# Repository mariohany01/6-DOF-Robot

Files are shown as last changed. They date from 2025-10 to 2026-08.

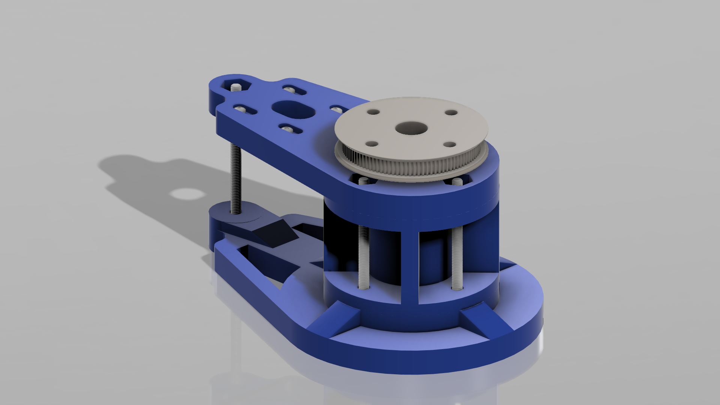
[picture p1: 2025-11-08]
Phase 1 Design, Kinematics & Core Theory (The Digital Foundation)/1 Conceptual Design & CAD/Pics/Joints/Base_Joint.png

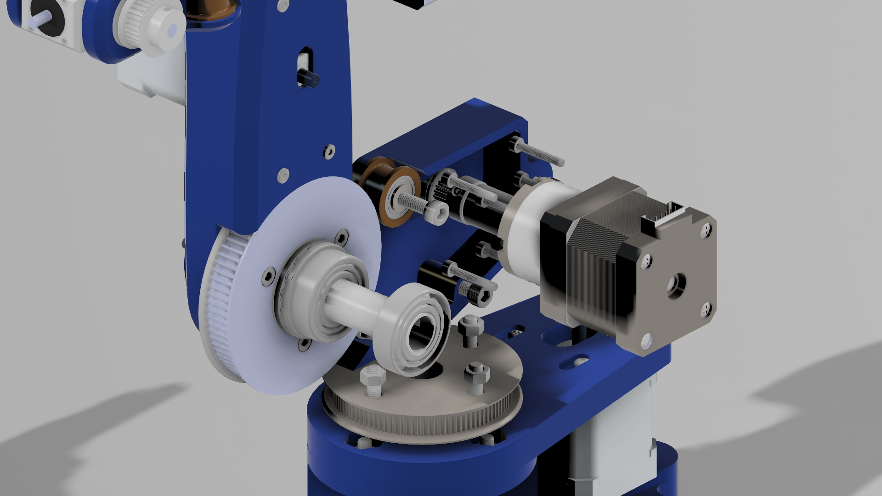
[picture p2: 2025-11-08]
Phase 1 Design, Kinematics & Core Theory (The Digital Foundation)/1 Conceptual Design & CAD/Pics/My_Kuka_07.png

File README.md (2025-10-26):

# 6-DOF KUKA-Style Robotic Arm

This is an end-to-end open-source project to design, simulate, and build a 6-DOF (Degrees of Freedom) robotic arm inspired by the KUKA industrial robot.

The project is a public journal following a 19-step roadmap, covering the entire professional engineering pipeline from initial theory to a fully functional, ROS-controlled physical robot.

## Project Phases

This repository is organized according to the 5-phase project plan:

1.  **Phase 1: Design, Kinematics & Core Theory**
    * Conceptual Design & CAD.
    * Kinematic Modeling (DH Parameters).
    * Forward & Inverse Kinematics (FK/IK)
    * Jacobian, Singularities & Velocity Control.
    * Dynamics Modeling.
    * MATLAB GUI Application.

2.  **Phase 2: Simulation & Path Planning**
    * Trajectory Planning.
    * URDF Generation.
    * Multi-Platform Simulation.

3.  **Phase 3: Advanced Control & HIL**
    * Control System Theory.
    * Simulink & Simscape Model.
    * Model-in-the-Loop (MIL) / Hardware-in-the-Loop (HIL).

4.  **Phase 4: ROS Integration & Virtual Deployment**
    * ROS Environment Setup.
    * RViz & MoveIt! Setup.
    * Gazebo Simulation Integration.

5.  **Phase 5: Physical Build & ROS Deployment**
    * Fabrication & Assembly.
    * Hardware Interface.
    * Final System Deployment.
    * Teleoperation / "Sync" Mode.

## Tech Stack

* **CAD:** SolidWorks
* **Kinematics & Control Design:** MATLAB, Simulink, Simscape
* **Robotic OS:** ROS (Robot Operating System)
* **Simulation:** Gazebo, CoppeliaSim, RViz , RoboDK
* **Path Planning:** MoveIt!
* **Hardware:** Raspberry Pi, Stepper Motors, 3D Printed Parts
* **Core Programming:** Python, C++

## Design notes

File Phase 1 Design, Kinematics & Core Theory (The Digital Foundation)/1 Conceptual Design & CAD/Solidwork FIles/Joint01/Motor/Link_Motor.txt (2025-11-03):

https://ampere-electronics.com/product/nema17-stepper-motor-with-5-181-planetary-gearbox-17hs4401s-pg518/

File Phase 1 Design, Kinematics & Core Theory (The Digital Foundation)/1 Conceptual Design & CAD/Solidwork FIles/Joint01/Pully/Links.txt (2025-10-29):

Idler Pully

https://ampere-electronics.com/product/20teeth-gt2-idler-pulley-6mm-width-3mm-bore/

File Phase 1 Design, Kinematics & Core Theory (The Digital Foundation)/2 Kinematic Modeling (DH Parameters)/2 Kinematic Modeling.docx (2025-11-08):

# 2 Kinematic Modeling (DH Parameters)

To analyze the manipulator's motion, a kinematic model was developed using the Standard Denavit-Hartenberg (DH) convention [1]. The coordinate frames assigned to each of the six joints are illustrated in Figure 1. Based on this frame assignment, the manipulator's kinematic parameters were derived. The fixed link parameters are defined as:

a1=135.80mm, a2=160.00mm, a3=15.00mm

d1=37.50mm, d2=138.10mm,d3=28.20mm

The complete set of DH parameters for the joints is presented in Table 1.

i | θ | d | a | α
1 | θ 1 | d1 | a1 | 90°
2 | θ 2+90° | 0 | a2 | -180°
3 | θ 3 | 0 | a3 | -90°
4 | θ 4 | d2 | 0 | 90°
5 | θ 5 | 0 | 0 | -90°
6 | θ 6 | d3 | 0 | 0°

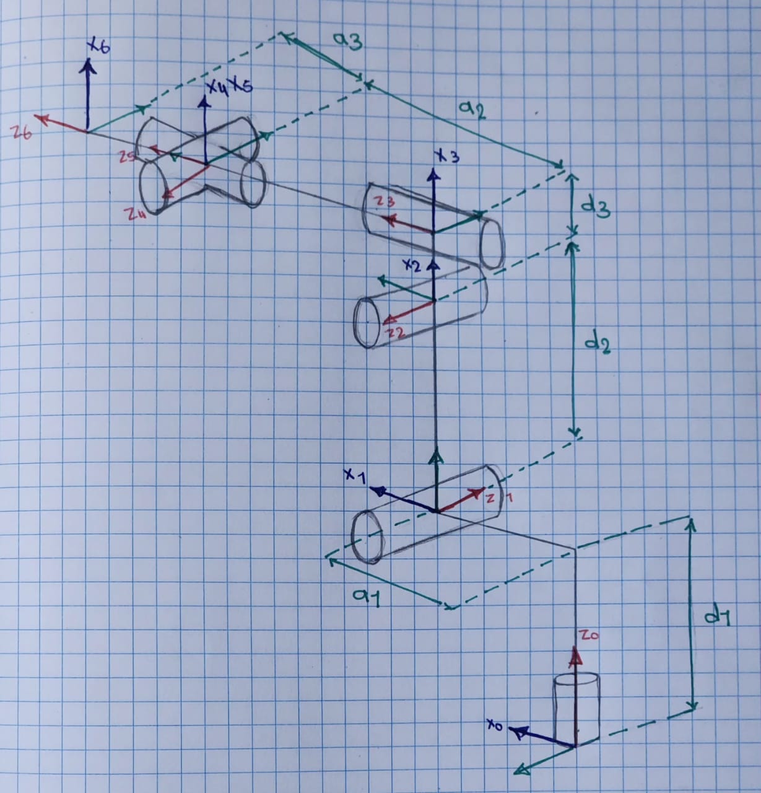
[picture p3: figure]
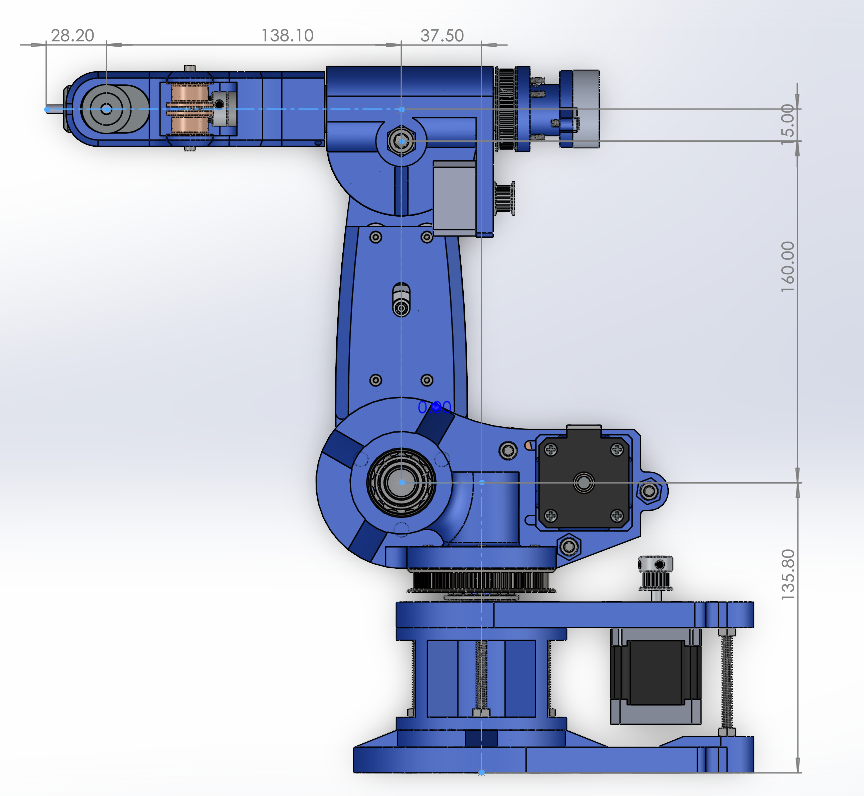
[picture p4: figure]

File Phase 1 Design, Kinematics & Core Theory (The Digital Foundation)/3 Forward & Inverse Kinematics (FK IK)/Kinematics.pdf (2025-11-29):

## FORWARD AND INVERSE KINEMATICS SOLUTION FOR 6-DOF MANIPULATORS WITH OFFSETS AND SPHERICAL WRISTS

## ABSTRACT

This research presents a comprehensive, analytical solution for the forward and inverse kinematics of a 6-DOF industrial robot, specifically focusing on a common configuration that includes both joint offsets and a spherical wrist. The forward kinematics solution is established using the standard Denavit-Hartenberg (DH) convention. For the inverse kinematics, a geometric solution is employed, which is chosen for its intuitive and interpretable nature. This method uses kinematic decoupling, solving the problem by dividing the manipulator into two 3-DOF mechanisms: the first three joints for positioning the wrist center, and the final three spherical wrist joints for orientation.

The primary contribution of this work is the validation of the geometric decoupling method against the forward kinematic model, demonstrating that the analytical approach yields exact solutions without the iterative errors inherent in numerical solvers.

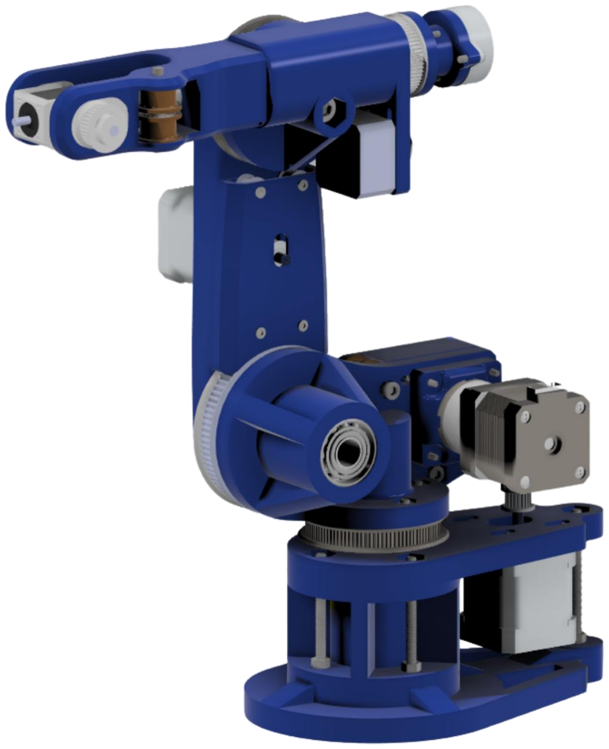
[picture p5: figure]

Eng Mario El-Assal

FORWARD AND INVERSE KINEMATICS SOLUTION FOR 6-DOF MANIPULATORS WITH OFFSETS AND SPHERICAL WRISTS

2 | Eng Mario El-Assal

## 1. INTRODUCTION

Industrial robotic manipulators are a critical component in modern automation, with 6-DOF (Degrees of Freedom) serial-chain arms, such as those from KUKA, representing common and versatile morphology. The effective implementation of any control system, motion planner, or simulation for these robots is fundamentally dependent on a precise and computationally efficient kinematic model. Kinematics, the description of motion without consideration of the forces and torques that cause it, provides the essential mapping between the robot's configuration in joint space and the pose of its end-effector in the operational task-space.

This paper presents the complete forward and inverse kinematic analysis of a custom-designed 6-DOF manipulator. The objective is to derive a robust mathematical model that serves as the foundation for future control and trajectory planning tasks.

The analysis is performed in a sequential manner. First, the robot's structure is parameterized using the Standard Denavit-Hartenberg (DH) convention. This process involves the systematic assignment of coordinate frames to each of the robot's six joints to derive a concise set of parameters (a, i, θ, α) that define the manipulator's geometry.

Second, these DH parameters are used to solve the Forward Kinematics (FK) problem. By developing the homogeneous transformation matrices for each link, the composite transformation from the robot's base frame to the end-effector frame is formulated. This allows for the direct computation of the end-effector's position and orientation for any given set of joint angles.

Finally, the Inverse Kinematics (IK) problem is addressed. This involves determining the set of joint angles (q1

. . . q2)
required to position the end-effector at a specific, desired pose (position and orientation) in its workspace.

### 1. Algebraic Solution

Solves the non-linear equations from the forward kinematics transformation Tn

0
(q) = Tdesired.
- Advantages: Robust and efficient for real-time use when a closed-form solution exists; independent of the DH convention; effective for simple manipulators (≤3 DOF).
- Limitations: Poor scalability—complexity grows exponentially with DOF and link offsets, making it impractical for most 6-DOF manipulators.

### 2. Geometric Solution

Decomposes the manipulator’s geometry into 2D trigonometric problems using the DH convention.

- Advantages: Fast and deterministic; widely used for 6-DOF manipulators (especially with spherical wrists); compatible with standard DH modeling.
- Limitations: Produces multiple valid solutions (e.g., elbow-up/down); must handle kinematic singularities where DOFs are lost.

### 3. Quaternion Solution

Uses 4D quaternions to represent and solve rotations.

- Advantages: Compact formulation; avoids gimbal lock; fewer equations.
- Limitations: Mathematically less intuitive; mainly suited for rotational systems; results less physically interpretable.

The resulting kinematic model provides the necessary foundation for all higher-level tasks, including singularity analysis, trajectory planning, and the future development of dynamic controllers for the manipulator.

Given that the kinematic structure under study involves rotational motion for each degree of freedom (DOF), employing a quaternion-based formulation would provide the most mathematically robust representation. However, for the purposes of clarity and intuitive understanding, this paper adopts a geometric solution approach. Although the robot joints exist in three-dimensional space, they are projected onto a single plane to simplify the analytical process. The spatial separations between consecutive joints are referred to as offsets. The exampled manipulator features two such offsets: one located between the first and second joints, and another between the third and fourth joints.

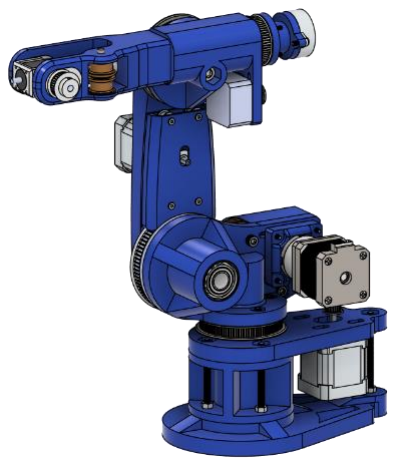
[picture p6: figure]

Figure 1. An example robot CAD model

The fourth, fifth, and sixth joints collectively constitute a spherical wrist configuration. Accordingly, the six-degree-of-freedom (6-DOF) manipulator is decomposed into two subsystems: the first comprising joints one through three, and the second encompassing the spherical wrist assembly. It is important to note that the inverse kinematics (IK) of such systems inherently yield multiple possible joint configurations for a given end-effector pose. This phenomenon has been extensively addressed in prior research. In this study, only a single representative solution is presented—specifically, the one that provides the broadest and most continuous range of motion across the manipulator’s workspace.

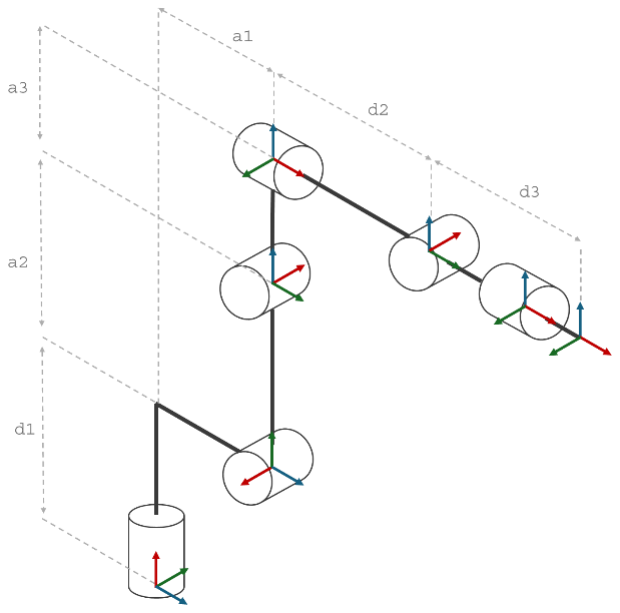
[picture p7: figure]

Figure 2. Schematic of robot shown at Figure 1

## 2. ROBOT VARIABLES, PARAMETERS & DENAVIT HARTENBERG TABLE

A very commonly used 6-DOF robot has the following variables, parameters, parameters and corresponding Denavit-Hartenberg (DH) table. In this section, these known and unknown will be exposed using the schematics in previous section.

### 2.1 Variables

The 6-DOF robot manipulator consists of six revolute joints, each providing one rotational degree of freedom. By adjusting the rotation of these joints, the robot can position its end-effector to perform the desired tasks. The primary kinematic variables of the system are the six revolute joint angles, denoted as θ. At the home position, all joint angles are defined as 0°, and during operation each angle must remain within the range of −180° to +180°.

Through this paper and its supplementary materials, the following notation is used:

Subscript | Description
θ | Joint angle
n = 1 … 6 | Indicates the joint number, counted from the base (joint 1) to the end-effector (joint 6)
v | Variable joint angle (active rotation from home position)
ℎ | Home offset angle at the home position
f | Joint angle used in forward kinematics (includes both variable and home offset components)
i | Joint angle used in inverse kinematics (includes both variable and home offset components)

Table 1: Table of Subscripts

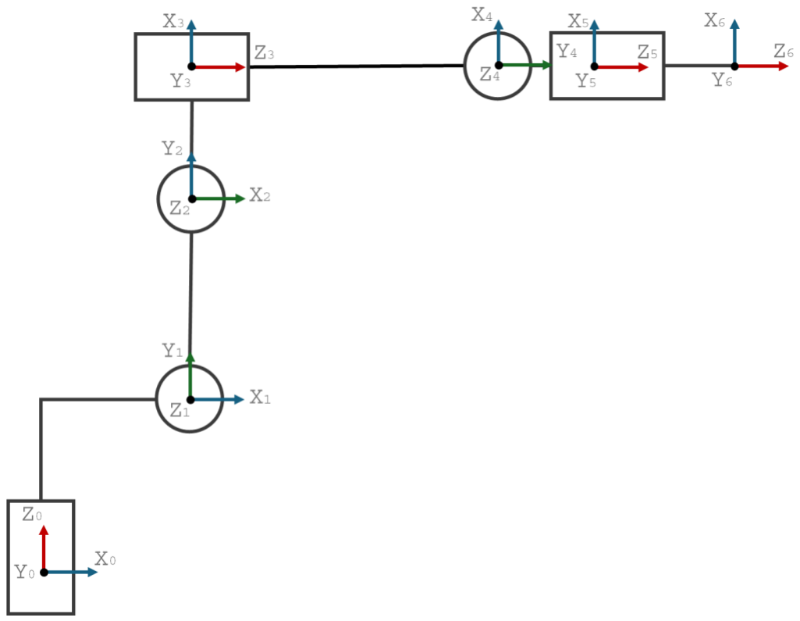
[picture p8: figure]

Figure 3: 2D Representation of schematics on Figure 2

### 2.2 Parameters & Denavit-Hartenberg Table

For the specified home position illustrated in Figures 2 and 3, the robot’s geometry is defined using the Denavit–Hartenberg (DH) convention. In this representation, each link and joint of the 6-DOF manipulator is described by four parameters: joint angle (θ), link twist (α), link offset (d), and link length (a). Each row of the DH table corresponds to one joint, resulting in a 6×4 table that fully characterizes the manipulator’s kinematic chain.

The definitions of the DH parameters are as follows:

- θ — Angle about the previous Z-axis, measured from the old X-axis to the new X-axis.
- α — Angle about the new X-axis, measured from the old Z-axis to the new Z-axis.
- d — Offset distance along the previous Z-axis, from the old joint to the new joint center.
- a — Length along the new X-axis, from the old joint to the new joint center.

When assigning local coordinate frames, the following conventions are applied:

- The Z-axis coincides with the joint axis — rotational for revolute joints or translational for prismatic joints.
- The X-axis is chosen to be perpendicular to both the previous and current Z-axes, intersecting them when possible.
- The Y-axis is determined according to the right-hand rule based on the orientations of the X and Z axes.

By following these conventions and using the geometric constraints illustrated in Figures 2 and 3, the complete DH parameter set of the robot manipulator (summarized in Table 1) can be derived. Proper placement and orientation of the local coordinate frames are critical steps in constructing the DH table, as they directly affect the simplicity and clarity of the kinematic model.

link(i) | θi | di | ai | αi
1 | θ1 | d1 | a1 | 90°
2 | θ2 + 90° | 0 | a2 | −180°
3 | θ3 | 0 | a3 | −90°
4 | θ4 | d2 | 0 | 90°
5 | θ5 | 0 | 0 | −90°
6 | θ6 | d3 | 0 | 0°

Table 2: D-H Parameters of robot manipulator that’s schematics shown in Figure 2&3

In summary, the forward kinematics of the manipulator are determined by treating each joint’s rotation angle as a variable. Since every joint is characterized by four Denavit–Hartenberg (DH) parameters, a 6-DOF robot has six joint variables and a total of 6×4 = 24 DH parameters that collectively define the end-effector’s position in Cartesian space (x, y, z) and its three orientation angles.

For forward kinematics analysis, these six joint variables always remain the fundamental unknowns, regardless of whether the mechanism has 2, 3, or 10 degrees of freedom. Increasing the number of DOF has minimal impact on the forward kinematics process; however, the same cannot be said for inverse kinematics. As the number of joints and their configurations increase, the complexity of solving the inverse kinematics problem also grows, and certain analytical methods may no longer be applicable.

## 3. FORWARD KINEMATICS CALCULATION

In 1955, Denavit and Hartenberg introduced a matrix-based approach for systematically assigning coordinate frames to each link in a robotic manipulator. This method enables the precise description of both translational and rotational relationships between consecutive links. The kinematic model of the robot in this study is formulated according to the Denavit–Hartenberg (D-H) convention. The transformation between any two successive joints can be expressed by substituting the corresponding D-H parameters from the table into the transformation matrix, denoted as Aₙ, where:

Anf =
[
cos θnf | −sin θnf cos αnf | sin θnf sin αnf | anf cos θnf
sin θnf | cos θnf cos αnf | cos θnf sin αnf | anf sin θnf
0 | sin αnf | cos αnf | dnf
0 | 0 | 0 | 1 | ]

When known joint parameters are put into their corresponding place in this matrix, then the following matrices are obtained for each joint starting from the base (1) to the tip (6);

A1f = [

cos θ1f | 0 | sin θ1f | a1f cos θ1f
sin θ1f | 0 −cos θ1f | a1f sin θ1f
0 | 1 | 0 | d1
0 | 0 | 0 | 1

]

A2f = [

cos θ2f | sin θ2f | 0 | a2f cos θ2f
sin θ2f | cos θ2f | 0 | a2f sin θ2f
0 | 0 | −1 | 0
0 | 0 | 0 | 1

]

A3f = [

cos θ3f | 0 | −sin θ3f | a3f cos θ3f
sin θ3f | 0 | cos θ3f | a3f sin θ3f
0 | −1 | 0 | 0
0 | 0 | 0 | 1

]

A4f = [

cos θ4f | 0 | sin θ4f | 0
sin θ4f | 0 −cos θ4f | 0
0 | 1 | 0 | d2
0 | 0 | 0 | 1

]

A5f = [

cos θ5f | 0 | −sin θ5f | 0
sin θ5f | 0 | cos θ5f | 0
0 | −1 | 0 | 0
0 | 0 | 0 | 1

]

A6f = [

cos θ6f | −sin θ6f | 0 | 0
sin θ6f | cos θ6f | 0 | 0
0 | 0 | 1 d3
0 | 0 | 0 | 1

]

For abbreviation and simplicity following notation substitutions will be used throughout this article.

Cn = cos θn

Sn = sin θn

Cab = CaCb − SaSb

Sab = CaCb + SaSb

The total transformation matrix from the robot base to the hand is as follows:

Tf = A1fA2fA3fA4fA5fA6f = [

r11f | r12f | r13f | pxf
r21f | r22f | r23f | pyf
r31f | r32f | r33f | pzf
0 | 0 | 0 | 1

]

Therefore:

- r11f = ((s1s4 + c1c4C2−3

)c5 + s5s2−3c1)c6 +(s1c4 − s4c1C2−3 )s6
- r12f = −((s1s4 + c1c4C2−3

)c5 + s5s2−3c1)s6 + (s1c4 − s4c1C2−3 )c6
- r13f = −(s1s4 + c1c4C2−3

)s5 + s2−3c1c5
- r21f = −((−s1c4C2−3 + s4c1

)c5 − s1s5s2−3)c6 − (s1s4C2−3 + c1c4 )s6
- r22f = ((−s1c4C2−3 + s4c1

)c5 − s1s5s2−3)s6 − (s1s4C2−3 + c1c4 )c6
- r23f = (−s1c4C2−3 + s4c1

)s5 + s1s2−3c5
- r31f = −(s5C2−3 − s2−3c4c5

)c6 − s4s6s2−3
- r32f = (s5C2−3 −s2−3c4c5

)s6 − s4s2−3c6
- r33f = −s5s2−3c4 − c5C2−3
- pxf = a1c1 + a2c1c2 + a3c1C2−3 + d2s2−3c1 − d3s1s4s5 − d3s5c1c4C2−3 + d3s2−3c1c5
- pyf = a1s1 + a2s1c2 + a3s1C2−3 +d2s1s2−3 − d3s1s5c4C2−3 + d3s1s2−3c5 + d3s4s5c1
- pzf = a2s2 + a3s2−3 + d1 − d2C2−3 − d3s5s2−3c4 − d3c5C2−3

The forward kinematics solution yields a 4 x 4 homogeneous transformation matrix, Tf. The upper-left 3 x 3 submatrix, TRf, is the rotation matrix

TRf = [

r11f | r12f | r13f
r21f | r22f | r23f
r31f | r32f | r33f

]

This is the Vectorial Representation (The Rotation Matrix) , This matrix describes the orientation of the end-effector frame relative to the base frame by explicitly defining the end-effector's basis vectors (n, o, a) in base coordinates:

- The n⃗ vector [r11fr12fr13f]

T
: This is the X-axis of your robot's hand (the "normal" direction), as seen from the base
- The o vector [r21fr22fr23f]

T
: This is the Y-axis of your robot's hand (the "orientation" or side-to-side direction), as seen from the base
- The a vector [r31fr32fr33f]

T
: This is the Z-axis of your robot's hand (the "approach" direction), as seen from the robot's base²

While mathematically complete, this is a non-minimal and non-intuitive way to specify a desired orientation. The nine constrained values do not correspond to simple, independent rotations, making it difficult for a user to define a target.

The unit vector shows the direction of the X, Y, Z-axis at the robot tip according to the base coordinate system. However, the expectation is to express all of these in angular form rather than vectorial. Below find how to express tip rotation in ZY′Z′′ Euler and XY′Z′′ Tait-Bryan angles. The matrices used to calculate these angles are available from.

ZY′Z′′ Euler angles of the robot tip coordinate axis to the base coordinate axis (subscript e denotes Euler)

Zef = arctan2(

ayf

axf

)

Y′ef = arctan2(

√1 − azf
2

azf

)

Z′′ef = arctan2(

ozf

−nzf

)

The translation matrix from the base coordinate system of the robot to the tip of the robot:

TTf = [

pxf
pyf

pzf ]

The transformation matrix that both includes translation and ZY′Z′′ Euler angles can be represented as

Tef =

[

pxf
pyf
pzf

Zef

Y′ef
Z′′ef]

This concludes the forward kinematics calculation. In proceeding inverse kinematics calculations derived above Tef matrix will be taken as input and θn joint rotations will be derived.

## 4. INVERSE KINEMATICS CALCULATIONS

In the previous section, the end-effector pose in Cartesian space was obtained by substituting specific joint angles into the forward kinematics model. Industrial robots, however, operate in the opposite direction. A robot controller typically receives a desired end-effector position and orientation in space, and it must compute the joint variables that achieve this pose. Determining these joint angles is the task of inverse kinematics.

Inverse kinematics is inherently more complex than forward kinematics, as it often involves solving nonlinear equations, handling multiple possible solutions, and ensuring that the resulting joint configurations are physically feasible. For a 6-DOF articulated robot, such as the arm considered in this research, these challenges become more pronounced due to the coupled rotational axes and the geometric constraints of the mechanism.

In this section, the inverse kinematics problem is formulated using the transformation matrix of the end-effector, derived previously. The matrix elements of the final transformation Tef are now treated as known inputs, and all subscripts are redefined from f to i to emphasize their role as inverse-kinematics variables. Based on this formulation, the analytical approach for obtaining joint angles will be developed and discussed.

Tei =
[

pxi
pyi
pzi
Zei

Y′ei
Z′′ei]

Once the end-effector transformation matrix Tei is defined, the rotational angles for each joint can be obtained by reconstructing the full transformation matrix in reverse. The translational component is directly accessible: the elements [pxi, pyi, pzi]occupy the upper portion of the final column of the matrix. To determine the rotational component, the rotation matrix must be expressed in terms of the Euler angles supplied as inputs. The rotation sequence corresponding to the Z Y

′ Z

′′Euler convention provides the necessary formulation for this process.

By substituting the inverse-kinematics Euler angles into the appropriate elemental rotation matrices, the complete rotation matrix is obtained. Throughout this derivation, the index iis appended to all variables to distinguish them as inverse-calculation parameters. These substitutions and notational conventions form the basis for constructing the rotation matrix used to compute the joint variables of the 6-DOF robot.

To systematically address the inverse kinematics problem, the robot is decomposed into two functional subsystems. This approach follows the conventional separation of an articulated manipulator into its positioning structure and orientation structure. The natural division occurs at the spherical wrist, where the final three joint axes intersect at a single point. By isolating the wrist center, the first three joints are used to determine the position of this point, while the remaining three joints are responsible for achieving the desired end-effector orientation. Based on this decomposition, the inverse kinematics solution is derived sequentially. The joint variables associated with the positioning subsystem are solved first, starting with θ01, θ03, and θ02, as these angles directly influence the spatial placement of the wrist center. Once the wrist position is determined, the orientation subsystem is solved through θ05, θ04, and θ06, which collectively produces the required end-effector orientation. This structured solution order ensures clarity, reduces coupling between equations, and aligns with the kinematic characteristics of the 6-DOF robot.

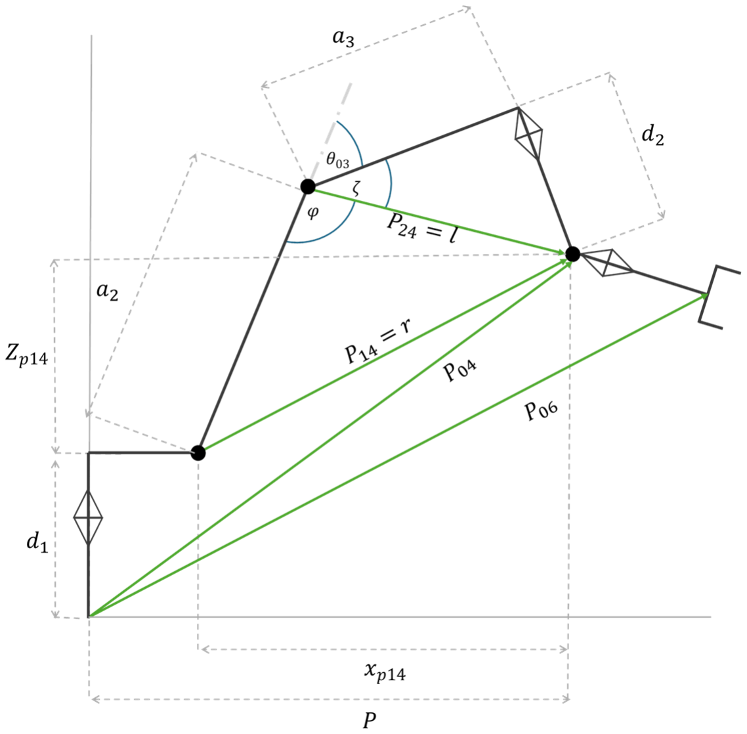
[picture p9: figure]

Figure 4: 2D Geometrical analysis for the robot

- For computational clarity, the following notation is adopted

Ann = [Rnn,nn

xnn
ynn
znn

]

Rnn,nn = [Ann,rx Ann,yx Ann,zx]

A01 = [

R01,11 | R01,12 | R01,13 | xnn
R01,21 | R01,22 | R01,23 | ynn
R01,31 | R01,32 | R01,33 | znn
0 | 0 | 0 | 1

]

A01,r = [A01,rx A01,yx A01,zx]

Pnn = [

xPnn
yPnn
zPnn

]

### 1. Solving for θ01

The wrist center position P04 is determined by deriving the input vectors from the given end-effector transformation Tei , extract the translation P06 = [pxi

, pyi

, pzi

]

T
and the end-effector z-axis unit vector a = [axi

, ayi

, azi

]

T
. The wrist centre P04(the origin of joint 4) is obtained by subtracting the end-effector offset along a:

P04 = P06 −P46

P04 = [

xP04
yP04
xP04

] = [
Pxi
Pyi

Pzi ]− d6i
[

r13
r23
r33

] = [
Pxi − d6ir13
Pyi −d6ir23

Pzi −d6ir33]

Subsequently, the angle of P04 relative to the XY-plane is calculated as

θ01 = θ01v = atan2 (
Pyi − d6ir23

Pxi − d6ir13) = atan2(yP04, xP04)

### 2. Solving for θ03

Among all six joint variables, θ03 is the most challenging to determine. Once the geometric reasoning behind θ03 is understood, the remainder of the inverse-kinematics solution becomes significantly more straightforward. To simplify this part of the geometry, a practical constraint is introduced on the allowable range of θ03, which reduces ambiguity and ensures a consistent solution for the robot configuration.

Based on law of cosines

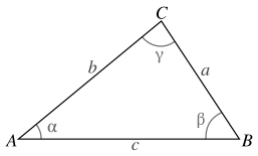
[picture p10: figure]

From the geometric projection in Figure 4, the following parameters are derived

- For P04 projection on the XY − Plane ∶ :

P = √xP04
2 +yP04

2

cos(α) =

c

2 + b

2 − c

2
2 × a × b

- For P14 projections:

xP14 = P − a1

zP14 = zP04 − d1

- Calculation of the radial distance r: r = √xP14
2 + zP14

2

- Finding the l :

l = √a3
2 + d2

2

- Using law of cosines:

c =

a2

2 + l

2 + r

2
2 × a2 × l

φ = arccos(c)

- Calculation of the fixed shoulder offset angle (ζ): ζ = atan2(d2
, a3

) = 83.8010°

- Therefore the elbow configuration:

θ03 = 180 − (φ + ζ)

### 3. Solving for θ02

- The angle θ2

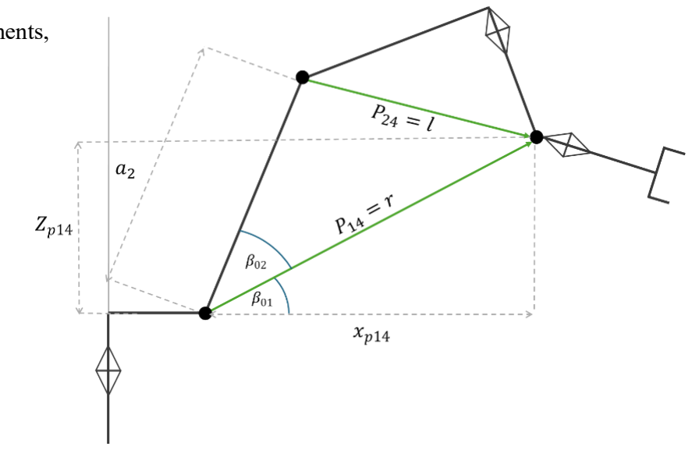
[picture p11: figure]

is decomposed into two components, β01and β02

- Finding beta 01

β01 = atan2(zp14, xp14)

- Finding beta 02

β02 = arccos (
a2

2 + r

2 +l

2
2 × a2 × r

)

- Finding theta 03

θ02 = β01 + β02

### 4. Solving for θ05

The joint angle θ5
is derived from the angle between the Z-axis of joint 4 and the z direction of joint 6
- Finding Z direction of 4th joint

A1i
= [
cos θ1f | 0 | sin θ1f | a1f cos θ1f
sin θ1f | 0 −cos θ1f | a1f sin θ1f
0 | 1 | 0 | d1
0 | 0 | 0 | 1

]

A2i
= [
cos θ2f | sin θ2f | 0 | a2f cos θ2f
sin θ2f | cos θ2f | 0 | a2f sin θ2f
0 | 0 | −1 | 0
0 | 0 | 0 | 1

]

A3i
= [
cos θ3f | 0 | −sin θ3f | a3f cos θ3f
sin θ3f | 0 | cos θ3f | a3f sin θ3f
0 | −1 | 0 | 0
0 | 0 | 0 | 1

]

A03i = A1i × A2i × A3i

- Therefore z03 =

A03,rz = [
c1

(s2c2 − c2s3

)
s1

(s2c2 − c2s3

)

−s23 ]

- And z06

A06,rz = [

r13
r23
r33

]

- Finding theta 05

θ05 = arccos(

A06,rz ⋅ A03,rz

|A06,rz||A03,rz|

)

### 5. Solving for θ04

A46i = A13i

−1 × A06i = [

Ix | Jx | Kx | Lx
Iy | Jy | Ky | Ly
Iz | Jz | Kz | Lz
0 | 0 | 0 | 1

]

- On the other hand

A46i = A4 × A5 × A6 = [

Ex | Fx | Gx | Hx
Ey | Fy | Gy | Hy
Ez | Fz | Gz | Hz
0 | 0 | 0 | 1

]

- Ex = c4c5c6 −s4s6
- Ey = c4s6 +c5c6c4
- Ez = c6s5
- Fx = −c6s4 − c4c5s6
- Fy = c4c6 −c5s4s6
- Fz = −s5s6
- Gx = −c4s5
- Gy = −s4s5
- Gz = c5
- Hx = −d3c4s5
- Hy = −d3s4s5
- Hz = d2 + d3c5
- For theta 04

θ04 = atan2 (

Ly
Lx

) +180°

### 6. Solving for θ06

θ06 = −atan2 (

Jz
IZ

)

## 5. CONCLUSION

This research presented a comprehensive analytical derivation of forward and inverse kinematics for a 6-DOF industrial manipulator featuring joint offsets and a spherical wrist. By employing the standard Denavit-Hartenberg (DH) convention, a forward kinematic model was established to successfully map joint space to Cartesian task space.

For the inverse kinematics, a geometric decomposition approach was utilized. This method effectively decoupled the positioning problem (joints 1–3) from the orientation problem (joints 4–6) by isolating the wrist center. This geometric strategy proved advantageous over algebraic or numerical iterative methods, offering a deterministic solution that accounts for the specific mechanical offsets found in KUKA-style architecture.

The resulting mathematical model provides a computationally efficient and physically interpretable framework for robot control. The validation of these equations establishes a robust foundation for high-level tasks. Future work will extend this kinematic model to implement real-time trajectory planning, singularity analysis, and dynamic control algorithms.

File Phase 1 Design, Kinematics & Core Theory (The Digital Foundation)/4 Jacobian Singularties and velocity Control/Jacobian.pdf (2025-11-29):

JACOBIAN AND VELOCITIES FOR 6-DOF MANIPULATORS WITH OFFSETS AND SPHERICAL WRISTS

## JACOBIAN AND VELOCITIES FOR 6-DOF MANIPULATORS WITH OFFSETS AND SPHERICAL WRISTS

## ABSTRACT

This research presents a comprehensive analysis of the differential kinematics for a specific 6-Degree of Freedom (DOF) Kuka serial manipulator. By defining the robot’s geometry through standard Denavit-Hartenberg (DH) parameters, we derive the forward kinematics model essential for state estimation. The core of this study focuses on the numerical computation of the Jacobian matrix, employing a finite difference approach to approximate the linear mapping between joint space velocities and task space end-effector velocities. Special attention is given to the derivation of angular velocity components using the properties of skew-symmetric matrices and the time derivative of rotation matrices. Furthermore, the practical utility of the Jacobian is demonstrated through a differential inverse kinematics control scheme, enabling precise Cartesian trajectory tracking. Detailed MATLAB implementations are dissected to illustrate the algorithmic translation of these theoretical concepts into functional simulation code.

## 1. INTRODUCTION

This research document analyzes the differential kinematics of a specific 6-Degree of Freedom (DOF) serial manipulator (Kuka-type). The focus is on the Jacobian Matrix, a critical mathematical tool that relates joint space velocities to task space (end-effector) velocities.

We will analyze the physical parameters of the robot, derive the mathematical foundation of the Numerical Jacobian, and provide a detailed, line-by-line illustration of the MATLAB implementation used for both Jacobian calculation and Inverse Kinematics control.

## 2. ROBOT DEFINITION AND KINEMATICS

### 2.1 Denavit-Hartenberg (DH) Parameters

The robot is defined using the Standard Denavit-Hartenberg parameters. These parameters describe the transformation from one link to the next.
link(i) | θi | di | ai | αi
1 | θ1 | d1 | a1 | 90°
2 | θ2 + 90° | 0 | a2 | −180°
3 | θ3 | 0 | a3 | −90°
4 | θ4 | d2 | 0 | 90°
5 | θ5 | 0 | 0 | −90°
6 | θ6 | d3 | 0 | 0°

### 2.2 Forward Kinematics (FK)

The position and orientation of the end-effector are determined by multiplying the transformation matrices of individual links:

Tglobal = A1

(q1

) · A2

(q2

) · A3

(q3

) · A4

(q4

) · A5

(q5

) · A6

(q6

)

Where each Ai

is a 4×4 homogeneous transformation matrix derived from row i of Table 1. The result is:

T = [

R3x3 | P3x1
01x3 | 1

]

## 3. THEORETICAL FOUNDATION: THE JACOBIAN

The Jacobian matrix serves as the fundamental mathematical bridge between the robot's internal joint space and the external Cartesian task space. It acts as a linear mapping operator that transforms joint velocities (q̇) directly into the end-effector's linear and angular velocities (υ, ω)by representing the matrix of partial derivatives, the Jacobian effectively linearizes the complex, non-linear forward kinematics equations around a specific operating point. This linearization is critical for differential control strategies, allowing us to calculate how infinitesimal changes in joint angles propagate to the tool tip's motion. Furthermore, the Jacobian provides essential insights into the mechanical structure, helping to identify singular configurations where the robot loses degrees of freedom.

### 3.1 What is the Jacobian Matrix?

To understand the Jacobian matrix, we must first revisit the fundamental concept of the derivative in a univariate context. Consider a single-variable function f(x) = x

2

.The derivative, denoted as df
dx

, represents the instantaneous rate of change of the function with respect to its input. For this specific function, the derivative is:

df
dx = x

2

This scalar value quantifies how the output responds to infinitesimal perturbations in the input x.

- Multivariable Scalar Functions:

Multivariable scalar functions expand into the multivariable domain; we encounter functions that accept multiple inputs simultaneously. Consider a scalar function f dependent on variables x1 and x2 defined as:

f(x1
, x2

) = x1

2 +3x1x2 + x2

2

In this context, we utilize the partial derivative to isolate the sensitivity of the function to a single variable while holding others constant. The gradient of this function is composed of its partial derivatives with respect to x1 and x2

∂f
∂x1

= 2x1 + 3x2

,

∂f
∂x2

= 3x1 + 2x2

- Vector-Valued Functions and the Jacobian:

The Jacobian matrix arises when we generalize this concept to vector-valued functions systems involving multiple input variables and multiple output functions. Let f(x) be a function mapping a vector x ∈ R

n
to a vector f ∈ R

m.
Consider the specific system defined by the vector function

f(x) = [

f1

(x1
, x2

)
f2

(x1
, x2

)

] = [

x1

2 + x2
x1 +x2

2

]

The Jacobian matrix, denoted as J, represents the linear mapping of the system's first-order partial derivatives. It describes how the output vector changes relative to changes in the input vector. For a system with two inputs and two outputs, the Jacobian is defined as:

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
By computing the partial derivatives for the system defined above:

Forf1
:

∂f1
∂x1

= 2x1 and ∂f1
∂x2

= 1

For f2
:

∂f2
∂x1

= 1 and ∂f2
∂x2

= 2x2

Substituting these terms into the matrix yields the final Jacobian for the system:

J(x) = [

2x1 | 1
1 | 2x2

]

### 3.2 Jacobian In robotics

In the domain of robotics, the Jacobian matrix (J) is not merely a mathematical abstraction but the fundamental operator connecting Joint Space (the internal configuration of motors and actuators) to the Task Space (the external position and orientation of the end-effector).

While Forward Kinematics defines a static relationship between joint angles and end-effector position, the Jacobian defines the dynamic relationship, mapping velocities and forces.

In the multivariable calculus section, we defined the Jacobian as a matrix of partial derivatives. In robotics, we apply this exact definition to motion.

The Core Equation:

v = J(q) × q̇

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
Where:

- v is the End-Effector Velocity Vector (6 × 1). It contains 3 linear velocities (vx

, vy, vz) and 3 angular velocities

(ωx, ωy, ωz).
- J(q) is the Jacobian Matrix (6 × 6 for your robot). It changes based on the robot's current pose q.
- q̇ is the Joint Velocity Vector (6 × 1). It represents how fast each motor is spinning (q1
̇ , q2

̇ , … , q6

̇ ).

What is Physical Interpretation for this part?
Each column i of the Jacobian tells you: "If I move only joint i at 1 rad/s, what is the resulting velocity vector of the end-effector?"

### 3.2.1 Calculating the Jacobian

While the Jacobian can be derived analytically, a robust method for computational implementation is the Numerical differentiation (Finite Difference) approach. This method approximates the partial derivatives by introducing a minute perturbation (δ) to each joint and observing the resulting change in the end-effector's pose.

- Step 1: Compute Initial State

First, we compute the Forward Kinematics (FK) for the current joint configuration q. This yields the homogeneous transformation matrix Tcurr

Tcurr = FK(q) = [

Rcurr | Pcurr
0 | 1

]

Where Pcurr is the position vector and Rcurr is the rotation matrix.

- Step 2: Apply Perturbation

To find the partial derivative with respect to joint i, we add a small perturbation δ (e.g., 10⁻⁶ ) to that specific joint
while keeping others constant:

qpert = q + [δ, 0,0,0,0,0]

- Step 3: Compute Perturbed State

We calculate the new Forward Kinematics based on the perturbed joints

Tpert = FK(qpert) = [

Rpert | TPert
0 | 1

]

- Step 4: Calculate Linear Velocity Component (Jv)

The linear velocity component of the Jacobian column is the rate of change of the position vector:

Jvi ≈

Ppert − Pcurr
δ

This approximates the derivative ∂P
∂qi
- Step 5: Calculate Angular Velocity Component (Jω)

Determining angular velocity requires analyzing the change in the Rotation Matrix. We compute the derivative of the rotation matrix Ṙ

Ṙ ≈

Rpert − Rcurr
δ

Using the property that Ṙ = S(ω)R,where S(ω)is the skew-symmetric matrix of the angular velocity vector , we can isolate S(ω)

S(ω) = ṘR
T

The resulting 3 × 3 Matrix S takes the form

S(ω) = [

0 | −wz | wy
wz | 0 | −wx
−wy | wx | 0

]

By applying the inverse operation (often denoted as the vex operator), we extract the angular velocity vector

Jωi = [ωx, ωy, ωz

]

T

Step 6: Construct the Column

The final i-th column of the Jacobian is the concatenation of the linear and angular components:

ji = [

jvi
jwi

]

This process is repeated for all n joints to construct the full 6 × n Jacobian matrix.

### 3.2.2 Inverse Kinematics Control (Resolved Rate Motion Control)

The Jacobian is instrumental in trajectory planning. While Forward Kinematics maps joint angles to positions, Inverse Kinematics typically seeks to find the joint angles required to reach a specific target. By utilizing the Jacobian, we can control the robot at the velocity level.

From the relationship ve = J(q)q̇, we can solve for the required joint velocities q̇ to achieve a desired end-effector

velocity vdesired:

q̇ = j

−1
(q) × vdesired

n practice, particularly for 6-DOF robots where singularities may occur, the Moore-Penrose Pseudoinverse (J

†
) is
preferred over the standard inverse to ensure numerical stability:

q̇ = J

†
(q) × vdesired

### 3.2.3 Algorithm Implementation

The implementation is developed in MATLAB. The simulation utilizes a numerical differentiation method to compute the Jacobian matrix dynamically at every time step, ensuring adaptability to the 6-DOF KUKA manipulator structure defined in the previous sections.

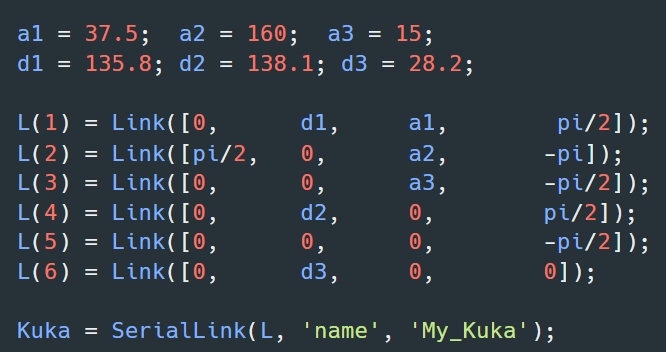
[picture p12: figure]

Block 1: Kinematic Modeling (DH Parameters)

The robot is modeled using the Denavit-Hartenberg
(DH) | convention. | The | link | parameters
( twist α, length a, offset d, and angle θ ) are defined to match the KUKA manipulator specifications.

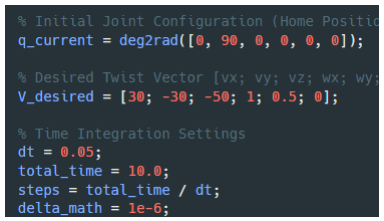
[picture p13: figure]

Block 2: Initialization and Target Definition

The simulation initializes the robot at a non-singular starting posture qcurrent . The control target is defined not as a final position, but as a velocity vector Vdesired ∈ R

6
, comprising
linear | velocity | (vx, vy, vz) and | angular | velocity

(ωx, ωy, ωz).

Block 3: The Control Loop & Numerical Jacobian

The core of the algorithm runs inside a temporal loop. At each step t, the Jacobian matrix J(q) is computed using the Finite Difference Method. Each joint is perturbed by a small delta (δ), and the resulting change in the end-effector pose is measured to approximate the partial derivatives.

Once $J$ is found, the required joint velocities are calculated using the Moore-Penrose pseudoinverse:

q̇ = J

†
(q) × vdesired

At the end

q_current = q_current + (q_dot' * dt);

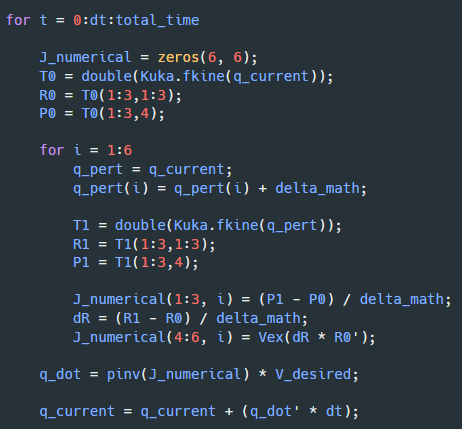
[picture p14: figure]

“You are taking the instantaneous velocity (q̇), pretending it stays constant for a tiny fraction of a

### second (dt), and "teleporting" the robot to that new spot.”

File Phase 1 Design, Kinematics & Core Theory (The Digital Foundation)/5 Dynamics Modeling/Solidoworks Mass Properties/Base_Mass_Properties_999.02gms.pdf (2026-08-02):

Mass properties of Base_Assembly Configuration: Default
Coordinate system: Base_Coordinates

Mass = 999.02 grams

Volume = 484030.20 cubic millimeters

Surface area = 166100.45 square millimeters

Center of mass: ( millimeters )
X = -36.09
Y = 0.11
Z = 41.05

Principal axes of inertia and principal moments of inertia: ( grams * square millimeters ) aTken at the center of mass.
Ix = ( 0.99, 0.00, -0.13) | Px = 1024124.32
Iy = (-0.13, 0.00, -0.99) | Py = 2453441.82
Iz = ( 0.00, 1.00, 0.00) | Pz = 2734227.60

Moments of inertia: ( grams * square millimeters )
aTken at the center of mass and aligned with the output coordinate system. (Using positive tensor notation.)
Lxx = 1046850.94 | Lxy = -5081.33 | Lxz = -178732.64
Lyx = -5081.33 | Lyy = 2734212.13 | Lyz = 761.80
Lzx = -178732.64 | Lzy = 761.80 | Lzz = 2430730.67

Moments of inertia: ( grams * square millimeters )
aTken at the output coordinate system. (Using positive tensor notation.)
Ixx = 2730644.14 | Ixy = -9098.05 | Ixz = -1658910.47
Iyx = -9098.05 | Iyy = 5719187.48 | Iyz = 5331.03
Izx = -1658910.47 Izy = 5331.03 | Izz = 3731937.63

One or more components have overridden mass properties: M5_ISO (4762)_70<91290A201>
M5_ISO (4762)_70<91290A201>
M5_ISO (4762)_70<91290A201> M5_ISO (4762)_70<91290A201> M5_ISO (4762)_70<91290A201> M3_ISO (4762)_10<92000A120> M3_ISO (4762)_10<92000A120> M3_ISO (4762)_10<92000A120> M3_ISO (4762)_10<92000A120> M5_ISO (4032)_Nut<90591A260> M5_ISO (4032)_Nut<90591A260> M5_ISO (4032)_Nut<90591A260> M5_ISO (4032)_Nut<90591A260> M5_ISO (4032)_Nut<90591A260> M5_ISO (4032)_Nut<90591A260> M5_ISO (4032)_Nut<90591A260> M5_ISO (4032)_Nut<90591A260> M5_ISO (4032)_Nut<90591A260>
M5_ISO (4032)_Nut<90591A260>
M5_ISO (4032)_Nut<90591A260>
Angular Contact Bearing (7002) 15x32x9<2385K42> Thrust ball bearing (51104) 20x35x10<7806K716> Thrust ball bearing (51104) 20x35x10<7806K716> Angular Contact Bearing (7002) 15x32x9<2385K42>

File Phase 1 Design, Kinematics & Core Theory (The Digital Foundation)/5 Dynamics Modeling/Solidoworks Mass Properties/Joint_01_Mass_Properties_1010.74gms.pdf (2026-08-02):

Mass properties of Joint01_Assembly Configuration: Default
Coordinate system: Joint01_Coordinates

Mass = 1010.74 grams

Volume = 424785.42 cubic millimeters

Surface area = 154917.10 square millimeters

Center of mass: ( millimeters )
X = -57.76
Y = -5.77
Z = -23.13

Principal axes of inertia and principal moments of inertia: ( grams * square millimeters ) aTken at the center of mass.
Ix = ( 0.85, -0.10, 0.51) | Px = 1083454.18
Iy = ( 0.52, 0.11, -0.85) | Py = 2165094.13
Iz = ( 0.02, 0.99, 0.15) | Pz = 2463913.57

Moments of inertia: ( grams * square millimeters )
aTken at the center of mass and aligned with the output coordinate system. (Using positive tensor notation.)
Lxx = 1379194.99 | Lxy = -96653.51 | Lxz = 472553.44
Lyx = -96653.51 | Lyy = 2446919.81 | Lyz = -97922.48
Lzx = 472553.44 | Lzy = -97922.48 | Lzz = 1886347.08

Moments of inertia: ( grams * square millimeters )
aTken at the output coordinate system. (Using positive tensor notation.)
Ixx = 1953704.77 | Ixy = 240460.56 | Ixz = 1822940.41
Iyx = 240460.56 | Iyy = 6359628.08 | Iyz = 37085.71
Izx = 1822940.41 | Izy = 37085.71 | Izz = 5291953.15

One or more components have overridden mass properties: Idler_Assembly
M5_ISO (4762)_16<91290A232>
M5_ISO (4762)_16<91290A232> M5_ISO (4762)_16<91290A232> M5_ISO (4762)_16<91290A232> M5_ISO (4762)_30<91290A194> M5_ISO (4762)_30<91290A194> M5_ISO (4762)_40<91290A196> M4_ISO (4762)_20<91290A123> M4_ISO (4762)_20<91290A123> M4_ISO (4762)_20<91290A123> M4_ISO (4762)_20<91290A123> M3_ISO (4762)_20<91290A123> M3_ISO (4762)_20<91290A123> M3_ISO (4762)_20<91290A123> M3_ISO (4762)_20<91290A123> M5_ISO (4032)_Nut<90591A260> M5_ISO (4032)_Nut<90591A260> M5_ISO (4032)_Nut<90591A260> M5_ISO (4032)_Nut<90591A260> M5_ISO (4032)_Nut<90591A260>
M5_ISO (4032)_Nut<90591A260>
M5_ISO (4032)_Nut<90591A260>
Angular Contact Bearing (7002) 15x32x9<2385K42> Angular Contact Bearing (7002) 15x32x9<2385K42>
Thrust ball bearing (51104) 20x35x10<7806K716>
Contact ball bearing(F695) 5x13x4<4668K115>
17HS4401S-PG518 Stepper Motor with 5.18-1 Planetary Gearbox

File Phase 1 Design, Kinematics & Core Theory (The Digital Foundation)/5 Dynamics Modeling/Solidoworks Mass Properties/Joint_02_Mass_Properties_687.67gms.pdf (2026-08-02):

Mass properties of Joint02_Assembly Configuration: Default
Coordinate system: Joint02_Coordinates

Mass = 687.67 grams

Volume = 341496.18 cubic millimeters

Surface area = 135243.10 square millimeters

Center of mass: ( millimeters )
X = -90.56
Y = 0.00
Z = -50.83

Principal axes of inertia and principal moments of inertia: ( grams * square millimeters ) aTken at the center of mass.
Ix = ( 0.99, 0.00, -0.14) | Px = 355190.74
Iy = (-0.14, 0.00, -0.99) | Py = 1854079.85
Iz = ( 0.00, 1.00, 0.00) | Pz = 1913642.15

Moments of inertia: ( grams * square millimeters )
aTken at the center of mass and aligned with the output coordinate system. (Using positive tensor notation.)
Lxx = 384127.81 | Lxy = -23.76 | Lxz = -206242.83
Lyx = -23.76 | Lyy = 1913642.15 | Lyz = 23.52
Lzx = -206242.83 | Lzy = 23.52 | Lzz = 1825142.79

Moments of inertia: ( grams * square millimeters )
aTken at the output coordinate system. (Using positive tensor notation.)
Ixx = 2160985.20 | Ixy = -64.60 | Ixz = 2959368.75
Iyx = -64.60 | Iyy = 9330286.24 | Iyz = 0.60
Izx = 2959368.75 | Izy = 0.60 Izz = 7464929.50

One or more components have overridden mass properties: oTothless Pulley<4><Default>
oTothless Pulley<3><Default>
NEMA17 Stepper MotorAssembly M4_ISO (4762)_35<91290A173> M4_ISO (4762)_35<91290A173> M4_ISO (4762)_35<91290A173> M3_ISO (4762)_25<90358A120> M3_ISO (4762)_25<90358A120>
M3_ISO (4762)_25<90358A120>
M3_ISO (4762)_25<90358A120>
Contact ball bearing(627) 7x22x7<4481N35> Contact ball bearing(627) 7x22x7<4481N35>

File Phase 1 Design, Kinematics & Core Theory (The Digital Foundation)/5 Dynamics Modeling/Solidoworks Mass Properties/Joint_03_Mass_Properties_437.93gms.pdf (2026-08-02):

Mass properties of Joint03_Assembly Configuration: Default
Coordinate system: Joint03_Coordinates

Mass = 437.93 grams

Volume = 195653.96 cubic millimeters

Surface area = 67538.41 square millimeters

Center of mass: ( millimeters )
X = -18.68
Y = 5.37
Z = -10.61

Principal axes of inertia and principal moments of inertia: ( grams * square millimeters ) aTken at the center of mass.
Ix = (-0.64, -0.24, -0.73) | Px = 241372.52
Iy = (-0.70, 0.56, 0.44) | Py = 399414.91
Iz = ( 0.31, 0.79, -0.53) | Pz = 424982.29

Moments of inertia: ( grams * square millimeters )
aTken at the center of mass and aligned with the output coordinate system. (Using positive tensor notation.)
Lxx = 336996.04 | Lxy = 17757.31 | Lxz = 78065.99
Lyx = 17757.31 | Lyy = 406643.04 | Lyz = 38017.26
Lzx = 78065.99 | Lzy = 38017.26 | Lzz = 322130.64

Moments of inertia: ( grams * square millimeters )
aTken at the output coordinate system. (Using positive tensor notation.)
Ixx = 398983.23 | Ixy = -26203.92 | Ixz = 164895.37
Iyx = -26203.92 | Iyy = 608787.42 | Iyz = 13036.83
Izx = 164895.37 | Izy = 13036.83 | Izz = 487582.75

One or more components have overridden mass properties: Nema_14_stepper<1><Default>
M8_ISO (4762)_80_Part<96144A239>
M4_ISO (4762)_15<91290A306> M4_ISO (4762)_15<91290A306> M4_ISO (4762)_15<91290A306> M4_ISO (4762)_15<91290A306> M3_ISO (4762)_8_Part<91290A13> M3_ISO (4762)_8_Part<91290A13>
M3_ISO (4762)_8_Part<91290A13>
M3_ISO (4762)_8_Part<91290A13>
Angular Contact Bearing (7002) _Up_ 15x32x9<2385K42> Angular Contact Bearing (7002) _Up_ 15x32x9<2385K42>

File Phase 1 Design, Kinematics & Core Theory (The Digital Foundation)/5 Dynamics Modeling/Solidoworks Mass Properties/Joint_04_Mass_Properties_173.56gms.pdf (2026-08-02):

Mass properties of Joint04_Assembly Configuration: Default
Coordinate system: Joint04_Coordinates

Mass = 173.56 grams

Volume = 51610.05 cubic millimeters

Surface area = 37907.61 square millimeters

Center of mass: ( millimeters )
X = -0.03
Y = -193.39
Z = 0.00

Principal axes of inertia and principal moments of inertia: ( grams * square millimeters ) aTken at the center of mass.
Ix = ( 0.00, -1.00, 0.00) | Px = 26509.07
Iy = ( 0.00, 0.00, -1.00) | Py = 451259.48
Iz = ( 1.00, 0.00, 0.00) | Pz = 453606.15

Moments of inertia: ( grams * square millimeters )
aTken at the center of mass and aligned with the output coordinate system. (Using positive tensor notation.)
Lxx = 453606.15 | Lxy = 1.37Lxz = -0.07
Lyx = 1.37 Lyy = 26509.07 | Lyz = -10.05
Lzx = -0.07 | Lzy = -10.05 | Lzz = 451259.47

Moments of inertia: ( grams * square millimeters )
aTken at the output coordinate system. (Using positive tensor notation.)
Ixx = 6944985.08 | Ixy = 859.1 | Ixz = -0.07
Iyx = 859.11 | Iyy = 26509.19 | Iyz = 5.33
Izx = -0.07 | Izy = 5.33 Izz = 6942638.52

One or more components have overridden mass properties: Nema 14 Round stepper<1><Default>
Angular Contact Bearing (625) 5x16x5<4481N79> M4_ISO (4762)_20<91290A123>
M4_ISO (4762)_20<91290A123>
M4_ISO (4762)_20<91290A123>
M4_ISO (4762)_20<91290A123> M3.5_ISO (4762)_12<90358A124> M3.5_ISO (4762)_12<90358A124>

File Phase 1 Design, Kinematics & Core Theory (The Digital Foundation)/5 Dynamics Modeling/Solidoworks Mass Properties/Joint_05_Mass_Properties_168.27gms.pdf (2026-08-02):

Mass properties of Joint05_Assembly Configuration: Default
Coordinate system: Joint05_Coordinates

Mass = 168.27 grams

Volume = 88887.78 cubic millimeters

Surface area = 41816.69 square millimeters

Center of mass: ( millimeters )
X = 0.01
Y = -4.75
Z = -44.47

Principal axes of inertia and principal moments of inertia: ( grams * square millimeters ) aTken at the center of mass.
Ix = ( 0.00, 0.04, -1.00) | Px = 63269.85
Iy = ( 0.00, -1.00, -0.04) | Py = 183663.89
Iz = (-1.00, 0.00, 0.00) | Pz = 214783.46

Moments of inertia: ( grams * square millimeters )
aTken at the center of mass and aligned with the output coordinate system. (Using positive tensor notation.)
Lxx = 214783.40 | Lxy = -22.29 | Lxz = -72.40
Lyx = -22.29 | Lyy = 183460.47 | Lyz = -4944.94
Lzx = -72.40 | Lzy = -4944.94 | Lzz = 63473.33

Moments of inertia: ( grams * square millimeters )
aTken at the output coordinate system. (Using positive tensor notation.)
Ixx = 551301.64 | Ixy = -32.67 | Ixz = -169.54
Iyx = -32.67 | Iyy = 516186.20 | Iyz = 30577.88
Izx = -169.54 | Izy = 30577.88 | Izz = 67265.88

One or more components have overridden mass properties: Idler_Assembly
Idler_Assembly
Angular Contact Bearing (625) 5x16x5<4481N79> Angular Contact Bearing (625) 5x16x5<4481N79>

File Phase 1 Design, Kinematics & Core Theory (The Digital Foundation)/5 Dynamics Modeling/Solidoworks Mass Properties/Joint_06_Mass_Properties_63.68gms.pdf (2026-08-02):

Mass properties of Joint06_Assembly Configuration: Default
Coordinate system: EndEffector_Coordinates

Mass = 63.68 grams

Volume = 22481.34 cubic millimeters

Surface area = 10446.13 square millimeters

Center of mass: ( millimeters )
X = 0.00
Y = -2.65
Z = -24.44

Principal axes of inertia and principal moments of inertia: ( grams * square millimeters ) aTken at the center of mass.
Ix = ( 0.00, -0.98, -0.20) | Px = 6855.73
Iy = ( 0.00, 0.20, -0.98) | Py = 10015.35
Iz = ( 1.00, 0.00, 0.00) | Pz = 12822.27

Moments of inertia: ( grams * square millimeters )
aTken at the center of mass and aligned with the output coordinate system. (Using positive tensor notation.)
Lxx = 12822.27 | Lxy = 0.00Lxz = 0.02
Lyx = 0.00 Lyy = 6988.11 | Lyz = 633.04
Lzx = 0.02Lzy = 633.04 | Lzz = 9882.98

Moments of inertia: ( grams * square millimeters )
aTken at the output coordinate system. (Using positive tensor notation.)
Ixx = 51320.44 | Ixy = 0.00 Ixz = 0.02
Iyx = 0.00 Iyy = 45040.13 | Iyz = 4753.29
Izx = 0.02 Izy = 4753.29 | Izz = 10329.11

One or more components have overridden mass properties: Nema8 Stepperi (banggood.com)<1><Default>

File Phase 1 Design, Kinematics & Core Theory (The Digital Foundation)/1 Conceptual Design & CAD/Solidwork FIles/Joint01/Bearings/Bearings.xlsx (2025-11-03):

Name | Type | Units | ISO | Outter | Inner | Width
Angular Contact Bearings | Angular | 2 | 7002 | 32 | 15 | 9
Thrust ball bearing | Thrust | 1 | 51104 | 35 | 20 | 10
Contact Ball bearing | Conatact | 1 | F695 | 13 | 5 | 4
Precesion Ball bearing |  | 2 |  |  |  |  | https://store.fut-electronics.com/products/idler-pulley-kit | https://ampere-electronics.com/product/smooth-idler-pulley-wheel-kit/ | https://cncegy.com/index.php?route=product/product&product_id=1321 | Done

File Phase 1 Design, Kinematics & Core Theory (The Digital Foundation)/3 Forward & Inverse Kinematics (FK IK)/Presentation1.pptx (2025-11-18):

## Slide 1

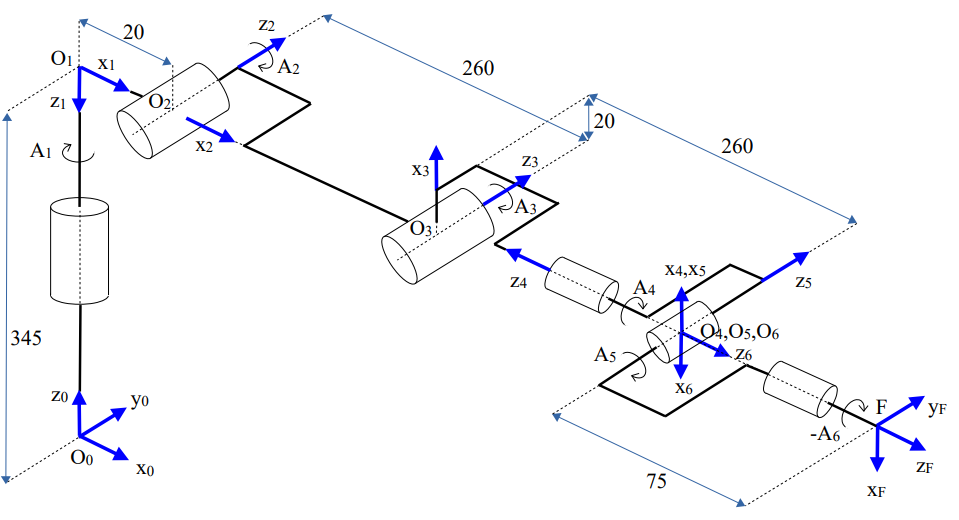
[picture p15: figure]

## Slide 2

a1

a3

d2

d3

a2

d1

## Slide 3

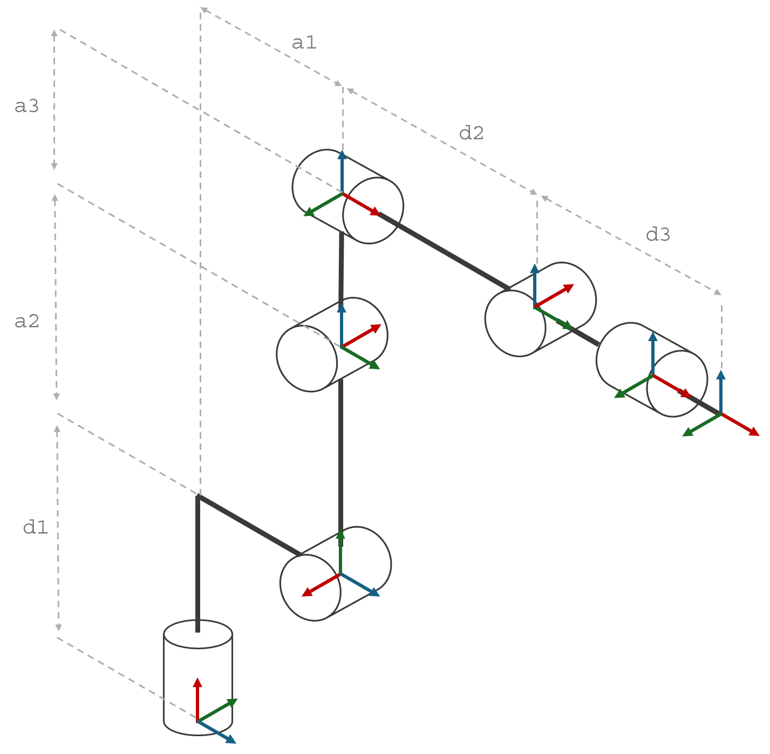
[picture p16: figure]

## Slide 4

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
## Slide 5

a_3

d_2

P_24 =l

a_2

θ_03

ζ

φ

Z_(p14)

P_14 =r

P_04

P_06

d_1

x_(p14)

P

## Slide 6

P_24 =l

a_2

β_02

Z_(p14)

P_14 =r

β_01

x_(p14)

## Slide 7

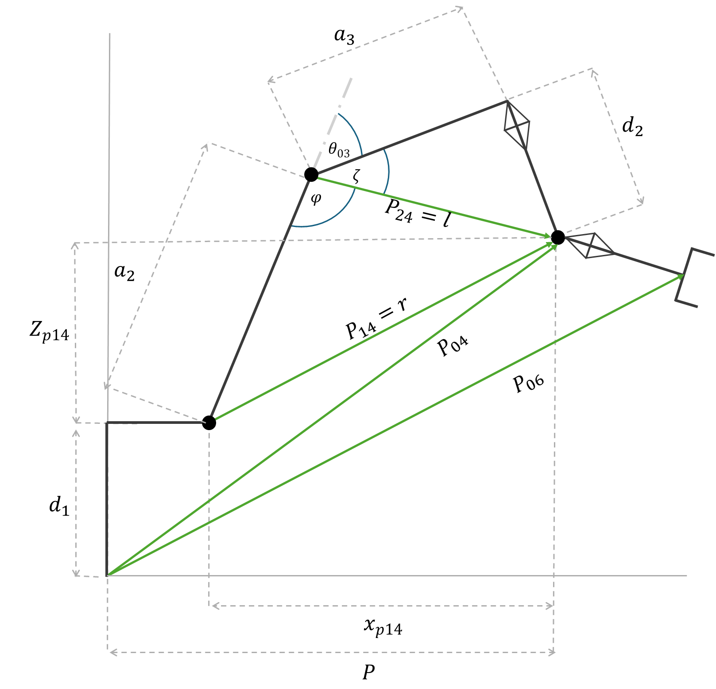
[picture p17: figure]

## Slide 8

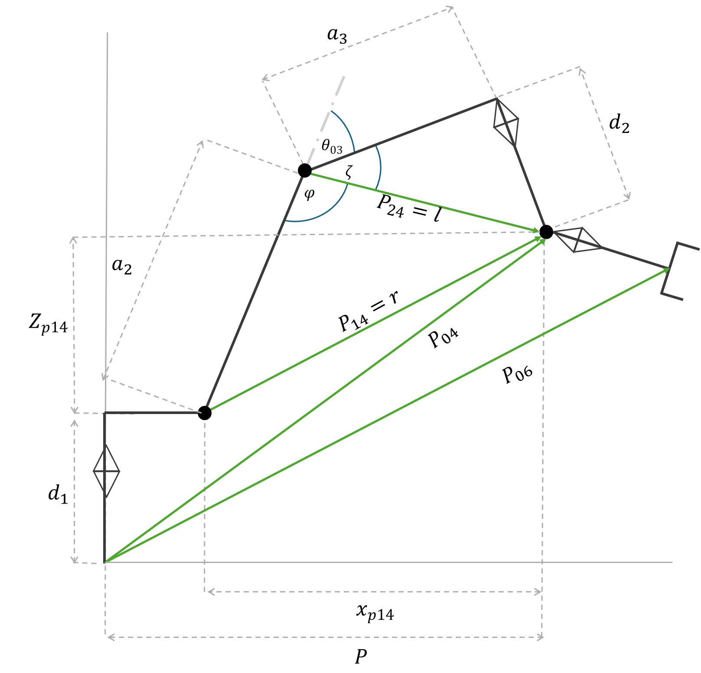
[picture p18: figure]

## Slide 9

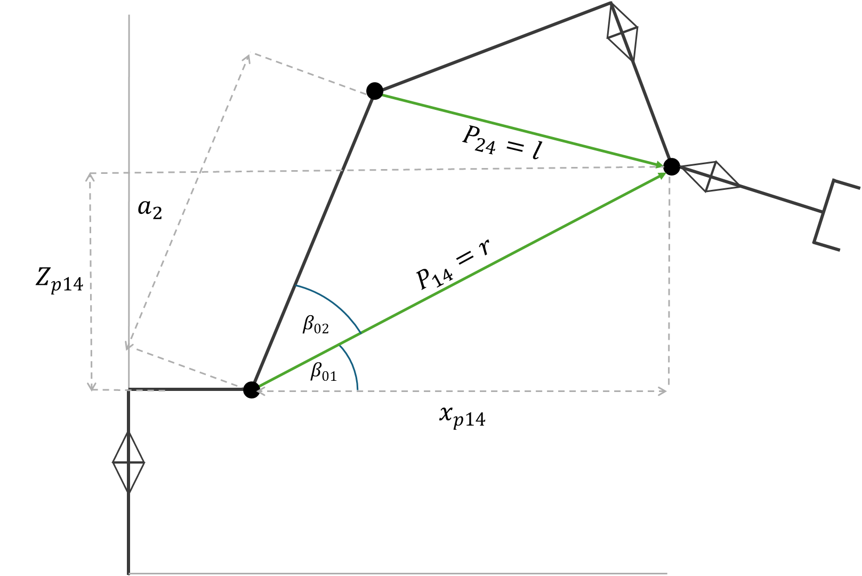
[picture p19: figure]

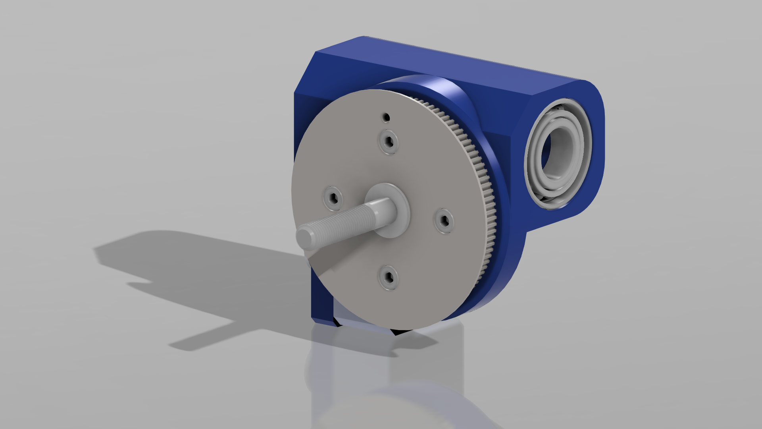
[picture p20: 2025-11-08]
Phase 1 Design, Kinematics & Core Theory (The Digital Foundation)/1 Conceptual Design & CAD/Pics/Joints/Joint_03_V1.png

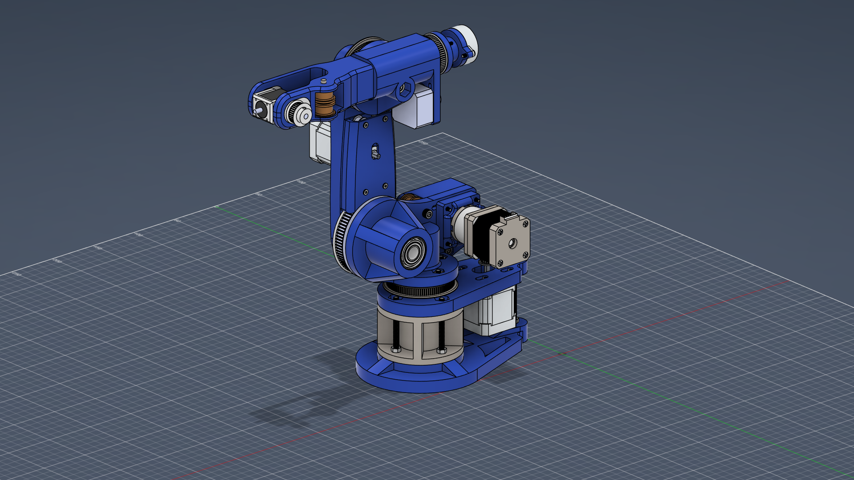
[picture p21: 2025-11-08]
Phase 1 Design, Kinematics & Core Theory (The Digital Foundation)/1 Conceptual Design & CAD/Pics/My_Kuka_Colored.png

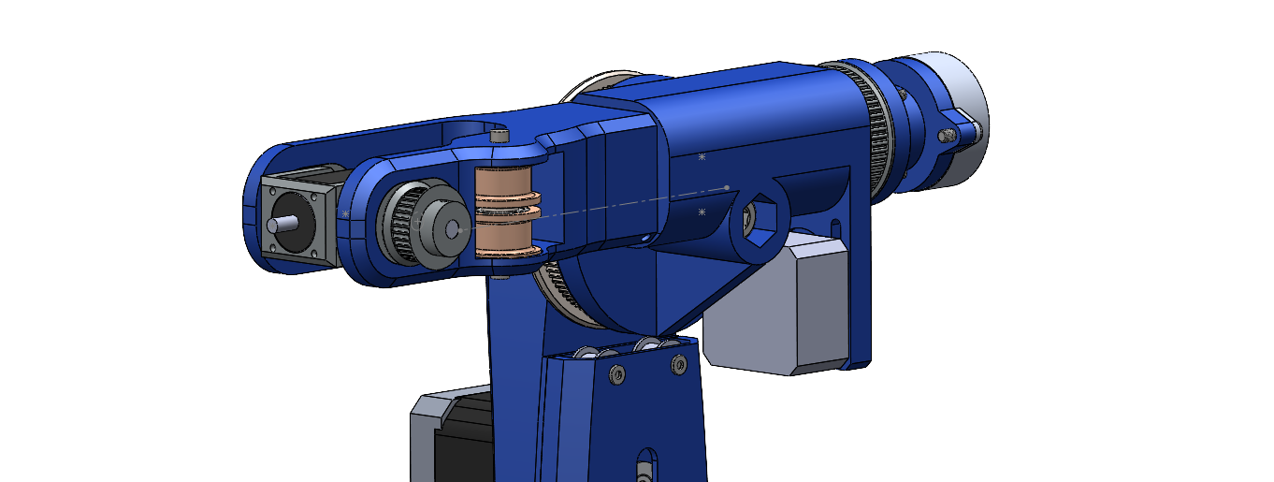
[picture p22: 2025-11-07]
Phase 1 Design, Kinematics & Core Theory (The Digital Foundation)/1 Conceptual Design & CAD/Pics/Solidworks Scerenshots/Screenshot 2025-11-07 162137.png

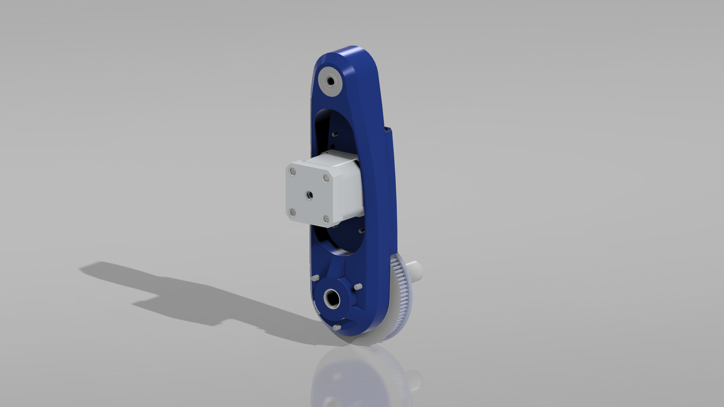
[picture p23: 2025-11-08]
Phase 1 Design, Kinematics & Core Theory (The Digital Foundation)/1 Conceptual Design & CAD/Pics/Joints/Joint_02_V2.png

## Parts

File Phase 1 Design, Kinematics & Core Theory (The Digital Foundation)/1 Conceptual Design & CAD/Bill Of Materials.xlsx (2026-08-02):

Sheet: 3d parts
Type |  | Name | # | Mass | Comment | Link
Base | Body | Bottom support | 1 | 230
 |  | Bottom Tube | 1 | 123
 |  | Base Plate | 1 | 114
 | Pulley | Nema 17 pulley | 1 | 5.5 | Timing Pulley GT2 (20 Teeth-5mm Inner Diameter-6mm Width) | https://store.fut-electronics.com/products/timing-pulley-gt2-20-teeth-5mm-inner-diameter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
Joint 01 | Body | Base Wall | 1 | 252.88
 |  | Motor Spacer | 1 | 27.07
 |  | BassWall Cover | 1 | 50
 |  | J1 Pulley Spacer | 1 | 8.48
 | Pulley | GT2 Pully 100 Teeth | 1
 |  | Nema 17 pulley | 1 | 5.5 | Timing Pulley GT2 (20 Teeth-5mm Inner Diameter-6mm Width) | https://store.fut-electronics.com/products/timing-pulley-gt2-20-teeth-5mm-inner-diameter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
 |  | Smooth Idler Pulley | 1 | 21.6 | Has 625 2RS (5mm Bore) | https://store.fut-electronics.com/products/idler-pulley-kit?_pos=1&_sid=9ef139122&_ss=r | Bearings are written again in the bearings Section
Joint 02 | Body | Arm_Joint_02 | 1
 |  | Cover_Arm_Joint_02 | 1
 |  | Spacer_Arm_Joint_02 | 1
 |  | Joint_02 GT2 Pully Spacer | 1
 | Pulley | Gt2 Pulley 80 Teeth | 1
 |  | Toothless Pulley | 2
 |  | Nema 17 pulley | 1 |  | Timing Pulley GT2 (20 Teeth-5mm Inner Diameter-6mm Width) | https://store.fut-electronics.com/products/timing-pulley-gt2-20-teeth-5mm-inner-diameter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
Joint 03 | Body | Arm_joint_03 | 1
 | Pulley | GT2 Pully 100 Teeth | 1
 |  | Nema 14 Pulley | 1 |  | Timing Pulley GT2 (20 Teeth-5mm Inner Diameter-6mm Width) | https://store.fut-electronics.com/products/timing-pulley-gt2-20-teeth-5mm-inner-diameter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
Joint 04 | Body | Motor Mount | 1
 | Pulley | GT2 Pulley 60 Teeth | 1
 |  | Nema 14 Round Pulley | 1 |  | Timing Pulley GT2 (20 Teeth-5mm Inner Diameter-6mm Width) | https://store.fut-electronics.com/products/timing-pulley-gt2-20-teeth-5mm-inner-diameter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
Joint 05 | Body | Joint 05 Arm | 1
 | Pulley | Smooth Idler Pulley | 2 |  | Has 625 2RS (5mm Bore) | https://store.fut-electronics.com/products/idler-pulley-kit?_pos=1&_sid=9ef139122&_ss=r | Bearings are written again in the bearings Section
Joint 06 | Body | Motor Mount | 1
 |  | GT2 Pulley 32 Teeth | 1

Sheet: Bearings
Joint | Type | Name | ISO | Quantity | Inner | Outter | Width | Links between |  | Links between |  | Mass
Base | Angular Contact | Angular Contact | 7002 | 2 | 15 | 32 | 9 | Bottom support | Bottom Tube | Base Plate | Bottom Tube | 30
 | Thrust | Thrust | 51104 | 2 | 20 | 35 | 10 | Bottom support | Bottom Tube | Base Plate | Bottom Tube | 37
Joint 01 | Angular Contact | Angular Contact | 7002 | 2 | 15 | 32 | 9 | Basewall | Shaft | Basewall | Shaft | 30
 | Thrust | Thrust | 51104 | 1 | 20 | 35 | 10 | Basewall | Shaft |  |  | 37
 | Contact Ball bearing | Contact Ball bearing | F695 | 1 | 5 | 13 | 4 | Shaft motor | Base Cover |  |  | 2.6
 | Precision Ball Bearing | Precision Ball Bearing | 625 | 2 | 5 | 16 | 5 | Idler Pulley |  | Idler Pulley |  | 5 | Calculated oin the idler
Joint 02 | Contact Ball bearing | Contact Ball bearing | 627 | 2 | 7 | 22 | 7 | Arm | Shaft J3 |  |  | 13
Joint 03 | Contact Ball bearing | Contact Ball bearing | 7002 | 2 | 15 | 32 | 9 | Maskein el shaft ek tawil f awelo |  |  |  | 30
Joint 04 | Contact Ball bearing | Contact Ball bearing | 625 | 1 | 5 | 16 | 5 | Akher el shaft el tawil
Joint 05 | Contact Ball bearing | Contact Ball bearing | 625 | 6 | 5 | 16 | 5 | El idlers ele haylef 3aleiha el belt |  | Shoaft el joint el Sades
 |  |  |  | 21
ISO | Quantity | Inner | Outer | Width | Price | Total Price
7002 | 6 | 15 | 32 | 9
51104 | 3 | 20 | 35 | 10
F695 | 1 | 5 | 13 | 4
627 | 2 | 7 | 22 | 7
625 | 9 | 5 | 16 | 5
 | 21 |  |  |  |  | 0

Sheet: Shafts
Joint | Name | Dimennsions |  | Joint
Joint 01 | Custmized shaft |  | Et2aked men shaft diameter bta3 el motor ashan frl data sheet kateb 8 msh 7.5 | Joint 01
 | Shaft | 5x40 | Lel idler | Joint 02
Joint 02 | Shaft | 96x15x13 | Ashan ylef el heta ele that | Joint 03 | washer | 8*16*1 | 1
Joint 03 | Shaft | M8 80 mm | Partialy threaded | Joint 04 | Washer | 15x20x1.2 | 1
Joint 04 | Shaft | 13x15x145 | For Joint 04 (The big one)
 | Shaft | 5x170 | For Joint 05
Joint 05 | Shaft | 5*40 | For idlers
Joint 06 | Saft | 5x30 | For Pulley
 |  | 5x13 | For Mounting

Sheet: Scews And Nuts
Joint | Type | ISO | Quantity | Length | Mass | Notes
Base | Screws | M5 | 5 | 70 | 13
 |  | M3 | 4 | 10 | 1.2
 | Nuts | M5 | 5 |  | 1.2
Joint 01 | Screws | M5 | 4 | 16
 |  | M5 | 2 | 30
 |  | M5 | 2 | 40 |  | Zawedt wahed momken ahtago badal el shaft ele 3al idler
 |  | M4 | 4 | 20
 |  | M3 | 4 | 20
 | Nuts | M5 | 8
 |  | M4 | 4 |  |  | Add them fel design
Joint 02 | Screws | M3 | 3 | 35
 |  | M3 | 4 | 25
 | Nuts | M4 | 3
Joint 03 | Sceews | M8 | 1 | 80 |  | Part thr
 |  | M4 | 4 | 15
 |  | M3 | 4 | 8
Joint 04 | Screws | M4 | 4 | 20
 |  | M3.5 | 2 | 12
 | Nuts | M4 | 4
 |  | M3.5 | 2
Joint 05 | Screws | M5 | 2 | 40 |  | Zawedt 2 momken ahtago badal el shaft ele 3al idler

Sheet: Motors
Joint | Motor | Dimenssions |  | Shaft Diameter | Shaft Length | Mass | Link | Price | Dimenssions |  | Shaft Diameter | Shaft Length | Link | Price
 |  | Hight | Face |  |  |  |  |  | Hight | Face
Base | Nema 17 | 47.3 | 42.3 | 5 | 24 | 308 | https://store.fut-electronics.com/products/stepper-motor-nema-17-2-kg-cm | 440
Joint 01 | Nema 17 Gear 5:1 | 72 | 42.3 | 8 | 17 |  | https://ampere-electronics.com/product/nema17-stepper-motor-with-5-181-planetary-gearbox-17hs4401s-pg518/ | 1800
Joint 02 | Nema 17 | 47.3 | 42.3 | 5 | 24 | 308 | https://store.fut-electronics.com/products/stepper-motor-nema-17-2-kg-cm | 440
Joint 03 | Nema 14 | NA | NA | NA | NA |  | NA | NA | 20 | 32.2 | 5 | 10.5
Joint 04 | Nema 14 | NA | NA | Na | NA |  | NA | NA
Joint 06 | NEMA 08 | NA | NA | NA | NA |  | NA | NA

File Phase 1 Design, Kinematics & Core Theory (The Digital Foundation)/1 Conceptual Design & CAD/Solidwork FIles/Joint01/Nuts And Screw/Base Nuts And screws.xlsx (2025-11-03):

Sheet: New
Screw/Nut | Part | Standard | Quantity | Thread Size | Length (mm) | Head Height (mm) | Screw Diameter | Head Diameter | Comment | Link
Screw | Pully washer body | ISO (4762) | 4 | M5 | 16 | 5 | 5 | 8.5 | Through it all | https://ampere-electronics.com/product/m5x16-hex-socket-head-screw/
 | Idler Compound | ISO (4762) | 1 | M5 | 40 | 5 | 5 | 8.5
 | Body - Cover | ISO (4762) | 2 | M5 | 30 | 5 | 5 | 8.5 | Ashan ymsek el 2 bba3d | https://ampere-electronics.com/product/m5x30-hex-socket-head-screw/
 | Motor - Space | ISO (4762) | 4 | M3 | 20 | 5 | 3 | 8.5 | Haymsek el motor bel spacer bta3ha haydkhol 9 fel motor we 8 fel spacer | https://ampere-electronics.com/product/m3x20-hex-socket-head-screw/
 | Spacer - Body | ISO (4762) | 4 | M4 | 20 | 4 | 4 | 8.5 | Spacer 15 mm 6 mm body | https://ampere-electronics.com/product/m4x25-hex-socket-head-screw/
Nut | Nut | ISO (4032) | 7 | M5 | 4 | NA | 5 | 8 | For the Screws | https://ampere-electronics.com/product/m5-galvanized-steel-hex-nut-pack-of-10/
Nut | Nut | ISO (4032) | 4 | M3 | 4 | NA | 5 | 8 | For the Screws
Nut | Nut | ISO (4032) | 4 | M4 | 4 | NA | 5 | 8 | For the Screws

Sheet: Old
Screw/Nut | Part | Standard | Quantity | Thread Size | Length (mm) | Head Height (mm) | Head Diameter | Comment
Screw | Base Screw (Socket) | ISO 4762 | 4 | M8 | 70 | 8 |  | To the circle
 | Base Bolt (Hex) | ISO 4014 | 1 | M8 | 80 | 5.3 |  | At the tip
 | Motor Screw | ISO 4762 | 4 | M3 | 10 | 3 |  | For The motor
Nut | Base Nut | ISO 4032 | 11 | M8 | N/A | 6.8 |  | 8*4 Circle - 3 For the tip

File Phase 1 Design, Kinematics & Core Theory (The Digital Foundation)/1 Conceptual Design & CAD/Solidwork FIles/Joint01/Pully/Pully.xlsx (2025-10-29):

Type | ISO | Comment | Link | McMaster
Belt | GT2 | GT2 Timing Belt black - Rubber. | https://store.fut-electronics.com/products/gt2-timing-belt-select-length?_pos=1&_sid=2a213407b&_ss=r
Servo Pulley | GT2 | Timing Pulley GT2 (20 Teeth-5mm Inner Diameter-6mm Width) | https://store.fut-electronics.com/products/timing-pulley-gt2-20-teeth-5mm-inner-diameter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
Idler Pulley | GT2 | 20Teeth GT2 Idler Pulley, 6mm Width, 3mm Bore | https://ampere-electronics.com/product/20teeth-gt2-idler-pulley-6mm-width-3mm-bore/
Idler Pulley | GT2 | 20Teeth GT2 Idler Pulley, 6mm Width, 5mm Bore | https://ampere-electronics.com/product/20teeth-gt2-idler-pulley-5mm-bore/ | https://www.mcmaster.com/products/idler-pulleys/timing-belt-idler-pulleys-2~/for-maximum-belt-width~6-mm/shaft-diameter~5-mm/

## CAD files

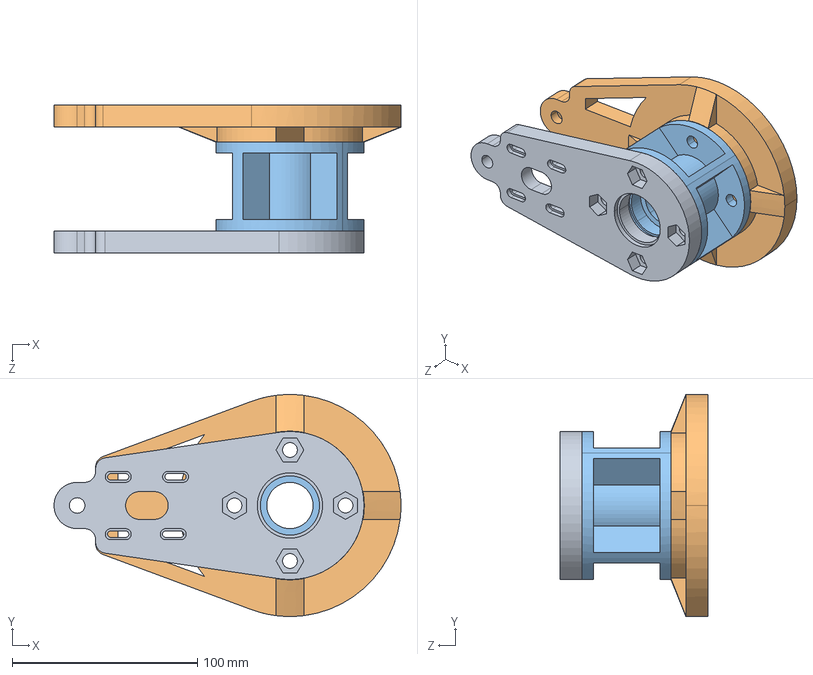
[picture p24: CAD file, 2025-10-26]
Phase 1 Design, Kinematics & Core Theory (The Digital Foundation)/1 Conceptual Design & CAD/Solidwork FIles/Base/STEP/Base_Assembly_Simple_STEP.STEP
187.5 x 120.0 x 80.0 mm
Base Plate
Bottom support_Mario
Bottom Tube

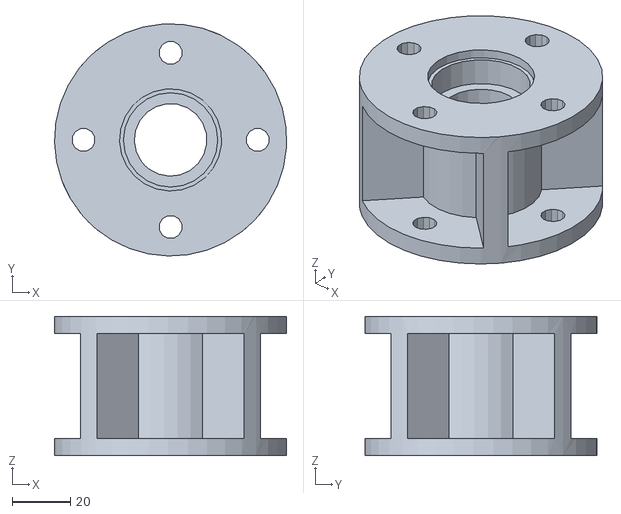
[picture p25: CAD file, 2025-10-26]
Phase 1 Design, Kinematics & Core Theory (The Digital Foundation)/1 Conceptual Design & CAD/Solidwork FIles/Base/STL/Base_Assembly_Simple - Bottom Tube-1.STL
79.9 x 79.9 x 48.0

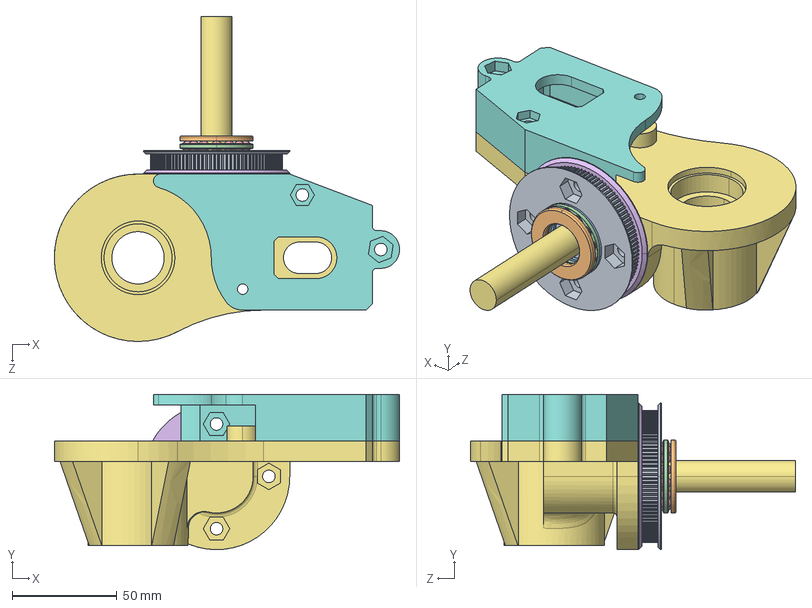
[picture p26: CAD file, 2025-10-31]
Phase 1 Design, Kinematics & Core Theory (The Digital Foundation)/1 Conceptual Design & CAD/Solidwork FIles/Joint01/STEP/Joint01_Assembly_Simple.STEP
165.0 x 74.2 x 155.3 mm
GT2 Pully 100 Teeth
Thrust ball bearing (51104) 20x35x10_7806K716
J1 Pulley Spacer
BaseWall
BaseWall Cover

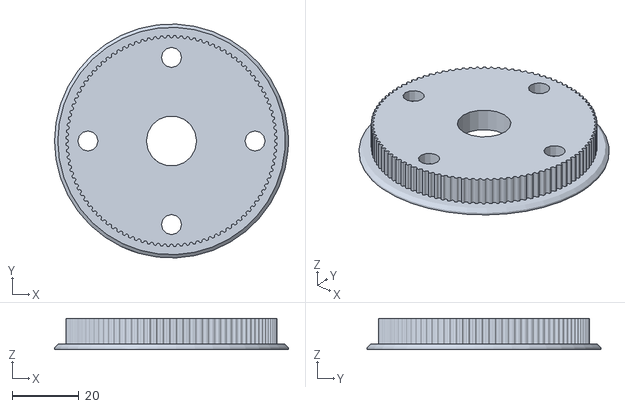
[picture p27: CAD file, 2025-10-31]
Phase 1 Design, Kinematics & Core Theory (The Digital Foundation)/1 Conceptual Design & CAD/Solidwork FIles/Joint01/STL/Joint01_Assembly_Simple - GT2 Pully 100 Teeth-1.STL
70.0 x 69.9 x 9.30

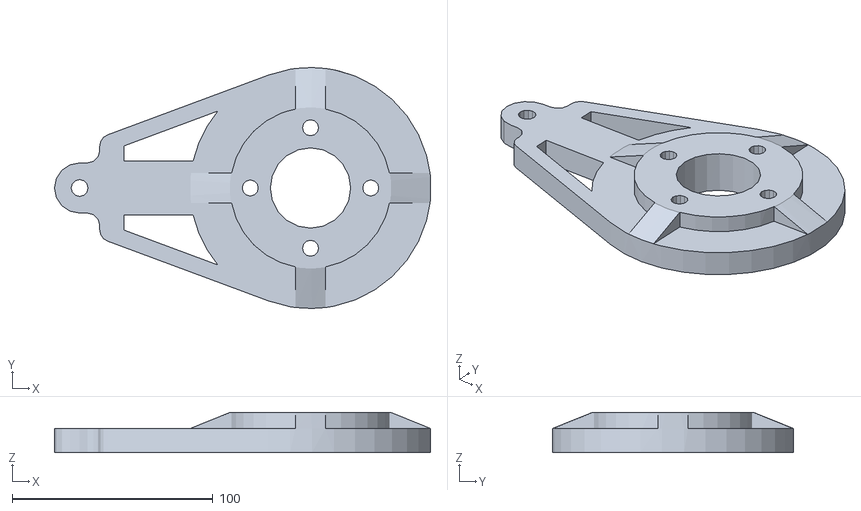
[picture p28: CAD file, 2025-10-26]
Phase 1 Design, Kinematics & Core Theory (The Digital Foundation)/1 Conceptual Design & CAD/Solidwork FIles/Base/STL/Base_Assembly_Simple - Bottom support_Mario-1.STL
187.2 x 120.0 x 20.0

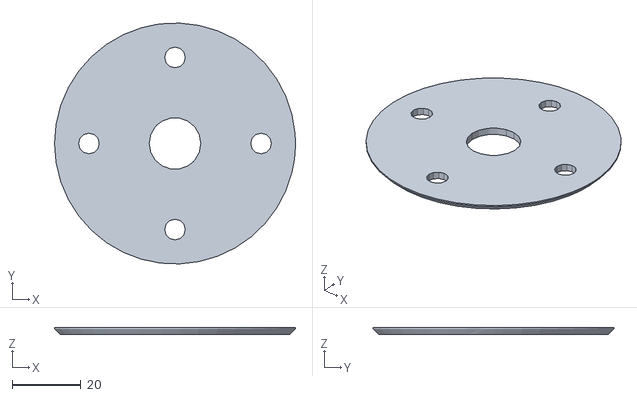
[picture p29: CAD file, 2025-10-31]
Phase 1 Design, Kinematics & Core Theory (The Digital Foundation)/1 Conceptual Design & CAD/Solidwork FIles/Joint01/STL/Joint01_Assembly_Simple - J1 Pulley Spacer-1.STL
70.0 x 69.9 x 2.00

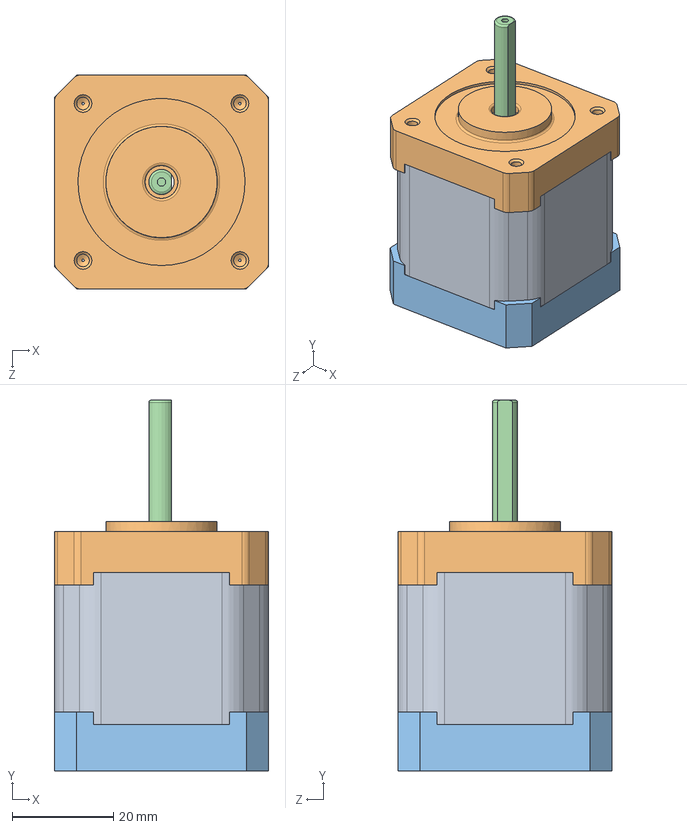
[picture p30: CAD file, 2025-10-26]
Phase 1 Design, Kinematics & Core Theory (The Digital Foundation)/1 Conceptual Design & CAD/Solidwork FIles/Joint02/Motor/NEMA 17 Stepper Motor Assembly.SLDASM
42.3 x 73.3 x 42.3 mm
NEMA 17 Stepper Motor Middle
NEMA 17 Stepper Motor Top
NEMA 17 Stepper Motor Bottom
NEMA 17 Stepper Motor Shaft
pan cross head_am x 4

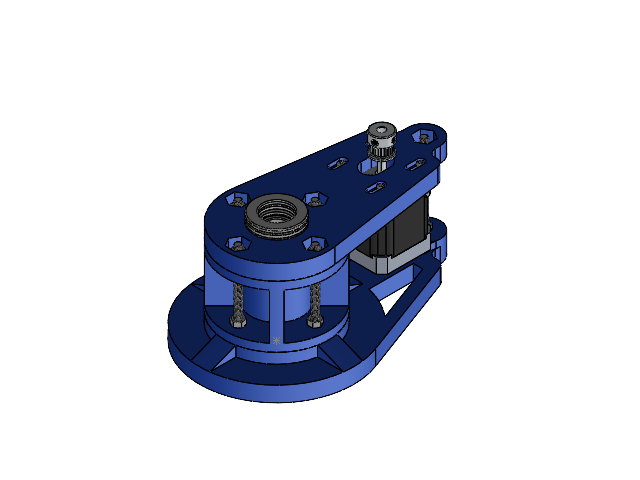
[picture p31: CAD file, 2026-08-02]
Phase 1 Design, Kinematics & Core Theory (The Digital Foundation)/1 Conceptual Design & CAD/Solidwork FIles/Base/Base_Assembly.SLDASM
Base Plate
Bottom support_Mario
Bottom Tube
NEMA 17 Stepper Motor Middle
NEMA 17 Stepper Motor Top
NEMA 17 Stepper Motor Bottom
NEMA 17 Stepper Motor Shaft
pan cross head_am x 4
M5_ISO (4762)_70 x 5
M3_ISO (4762)_10 x 4
M5_ISO (4032)_Nut x 11
Angular Contact Bearing (7002) 15x32x9 x 2
Thrust ball bearing (51104) 20x35x10 x 2
GT2_20T

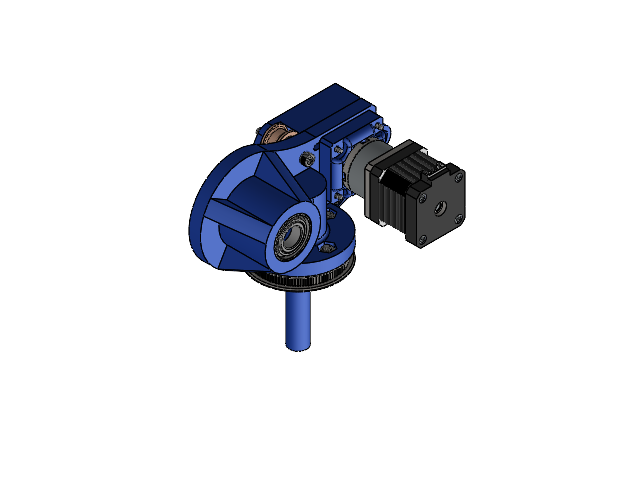
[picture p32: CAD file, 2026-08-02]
Phase 1 Design, Kinematics & Core Theory (The Digital Foundation)/1 Conceptual Design & CAD/Solidwork FIles/Joint01/Joint01_Assembly.SLDASM
GT2 Pully 100 Teeth
GT2_20T
Smooth Idler Pulley
4481N79_Precision Ball Bearing x 2
Precision Shim (Gasket) x 2
J1 Pulley Spacer
BaseWall
BaseWall Cover
Motor 02 spacer
M5_ISO (4762)_16 x 4
M5_ISO (4762)_30 x 2
M5_ISO (4762)_40
M4_ISO (4762)_20 x 4
M3_ISO (4762)_20 x 4
M5_ISO (4032)_Nut x 7
Angular Contact Bearing (7002) 15x32x9 x 2
Thrust ball bearing (51104) 20x35x10
Contact ball bearing(F695) 5x13x4
Nema 17HS4401-S
PG518 5.18-1 Planetary Gearbox
shaft

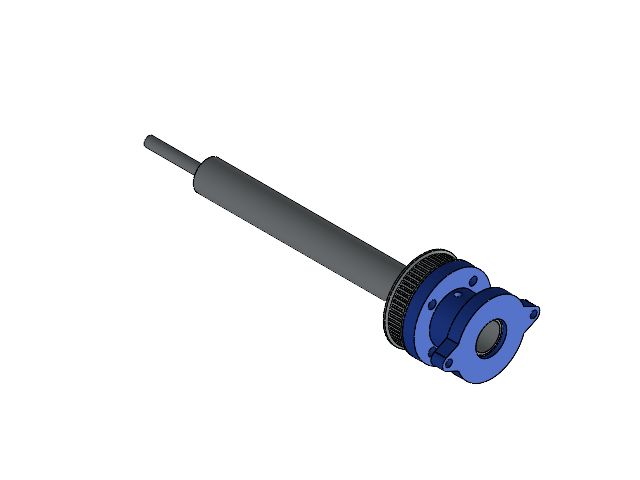
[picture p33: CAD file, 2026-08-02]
Phase 1 Design, Kinematics & Core Theory (The Digital Foundation)/1 Conceptual Design & CAD/Solidwork FIles/Joint04/Joint04_Assembly_Simple.SLDASM
Motor_Mount
GT2 Pully 60 Teeth
Washer_joint04_Motor
Shaft 13x15x145 - Joint 04
Shaft 5x170- joint 5

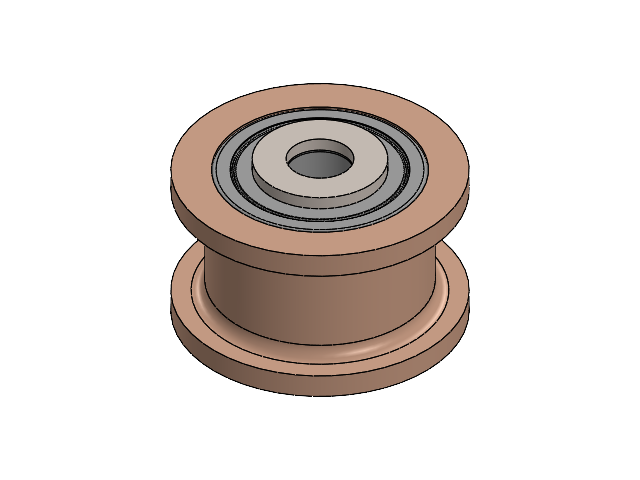
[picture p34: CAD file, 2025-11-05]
Phase 1 Design, Kinematics & Core Theory (The Digital Foundation)/1 Conceptual Design & CAD/Solidwork FIles/Joint05/Idler/Idler_Assembly.SLDASM
Smooth Idler Pulley
4481N79_Precision Ball Bearing x 2
Precision Shim (Gasket) x 2

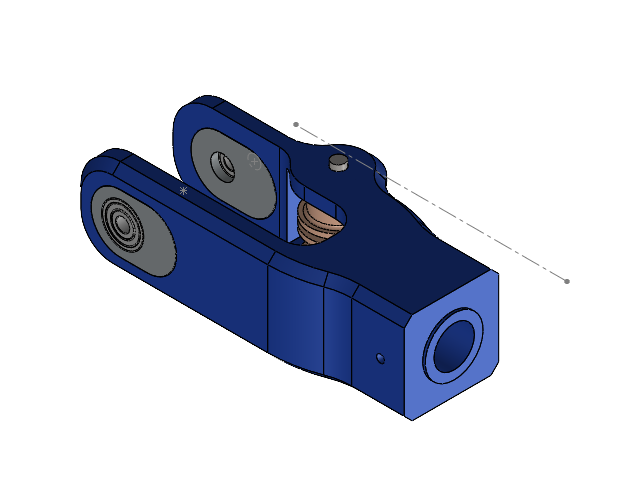
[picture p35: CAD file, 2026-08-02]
Phase 1 Design, Kinematics & Core Theory (The Digital Foundation)/1 Conceptual Design & CAD/Solidwork FIles/Joint05/Joint05_Assembly.SLDASM
Joint5 Arm
Mounting x 2
Smooth Idler Pulley x 2
4481N79_Precision Ball Bearing x 4
Precision Shim (Gasket) x 4
5mm_40mm_Shaft
Angular Contact Bearing (625) 5x16x5 x 2

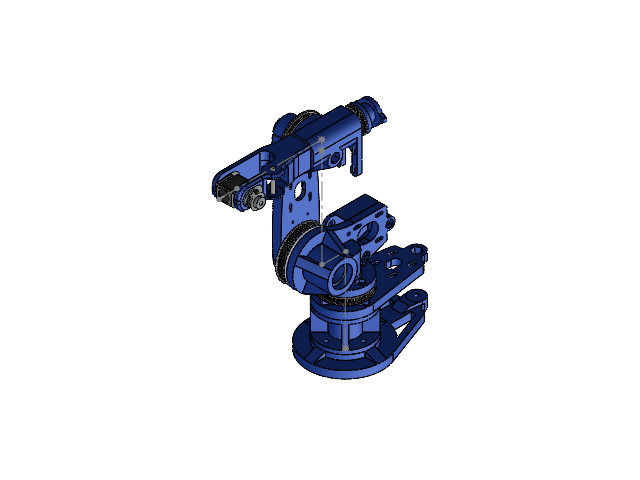
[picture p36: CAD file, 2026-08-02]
Phase 1 Design, Kinematics & Core Theory (The Digital Foundation)/1 Conceptual Design & CAD/Solidwork FIles/My_Kuka_Simple.SLDASM
Base Plate
Bottom support_Mario
Bottom Tube
GT2 Pully 100 Teeth
Thrust ball bearing (51104) 20x35x10 x 2
J1 Pulley Spacer
BaseWall
BaseWall Cover
Joint_02 GT2 Pully 80 Teeth
Joint_02 GT2 Pully Spacer
Arm_Joint_02
Arm_Joint_03
GT2 Pully 100 Teeth Top
washer_8x16x1.6
Motor_Mount
GT2 Pully 60 Teeth
Washer_joint04_Motor
Shaft 13x15x145 - Joint 04
Shaft 5x170- joint 5
Joint5 Arm
Mounting x 2
5mm_40mm_Shaft
Motor Mount
Shaft_02_5x30
Shaft_01_5x13
Nema8 Stepperi (banggood.com)
GT2 Pully 32 Teeth Top

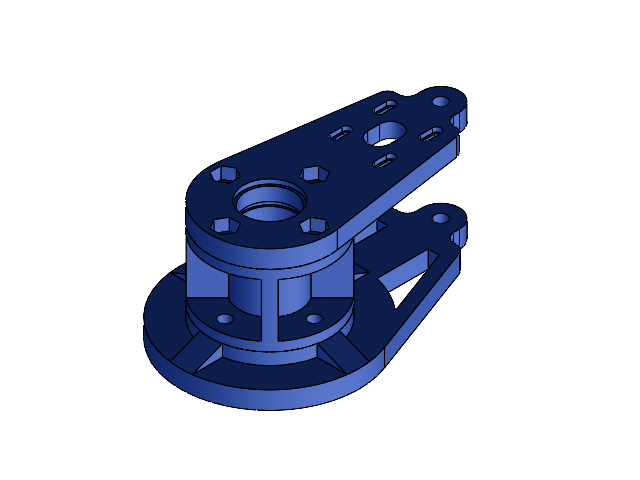
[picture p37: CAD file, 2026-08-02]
Phase 1 Design, Kinematics & Core Theory (The Digital Foundation)/1 Conceptual Design & CAD/Solidwork FIles/Base/Base_Assembly_Simple.SLDASM
Base Plate
Bottom support_Mario
Bottom Tube

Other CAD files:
Phase 1 Design, Kinematics & Core Theory (The Digital Foundation)/1 Conceptual Design & CAD/Solidwork FIles/Joint02/Joint02_Assembly_Simple.SLDASM
Phase 1 Design, Kinematics & Core Theory (The Digital Foundation)/1 Conceptual Design & CAD/Solidwork FIles/Joint03/Joint03_Assembly.SLDASM
Phase 1 Design, Kinematics & Core Theory (The Digital Foundation)/1 Conceptual Design & CAD/Solidwork FIles/Joint04/Joint04_Assembly.SLDASM
Phase 1 Design, Kinematics & Core Theory (The Digital Foundation)/1 Conceptual Design & CAD/Solidwork FIles/Joint06/Joint06_Assembly.SLDASM
Phase 1 Design, Kinematics & Core Theory (The Digital Foundation)/1 Conceptual Design & CAD/Solidwork FIles/Base/Base Plate.SLDPRT
Phase 1 Design, Kinematics & Core Theory (The Digital Foundation)/1 Conceptual Design & CAD/Solidwork FIles/Base/Bottom Tube.SLDPRT
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

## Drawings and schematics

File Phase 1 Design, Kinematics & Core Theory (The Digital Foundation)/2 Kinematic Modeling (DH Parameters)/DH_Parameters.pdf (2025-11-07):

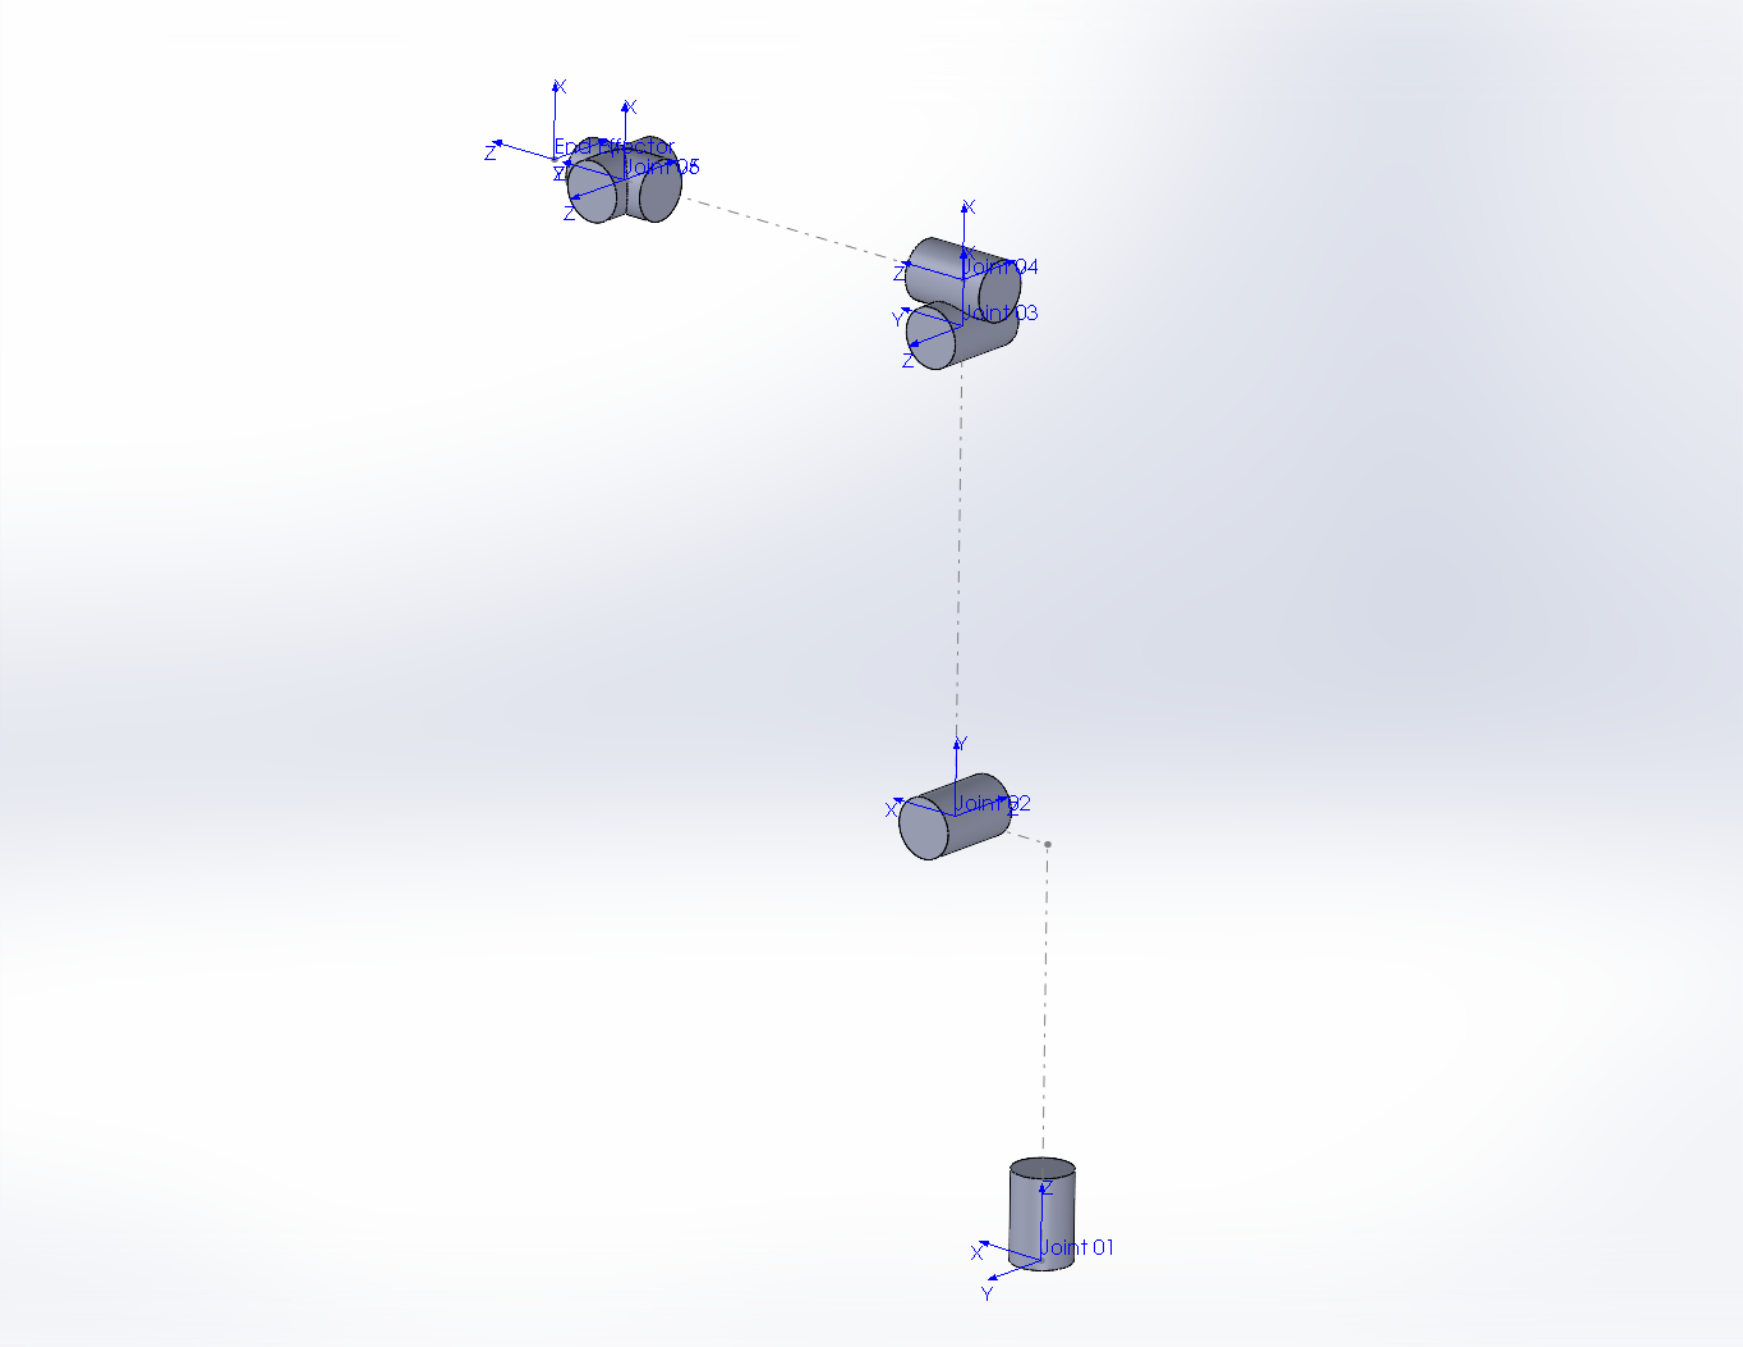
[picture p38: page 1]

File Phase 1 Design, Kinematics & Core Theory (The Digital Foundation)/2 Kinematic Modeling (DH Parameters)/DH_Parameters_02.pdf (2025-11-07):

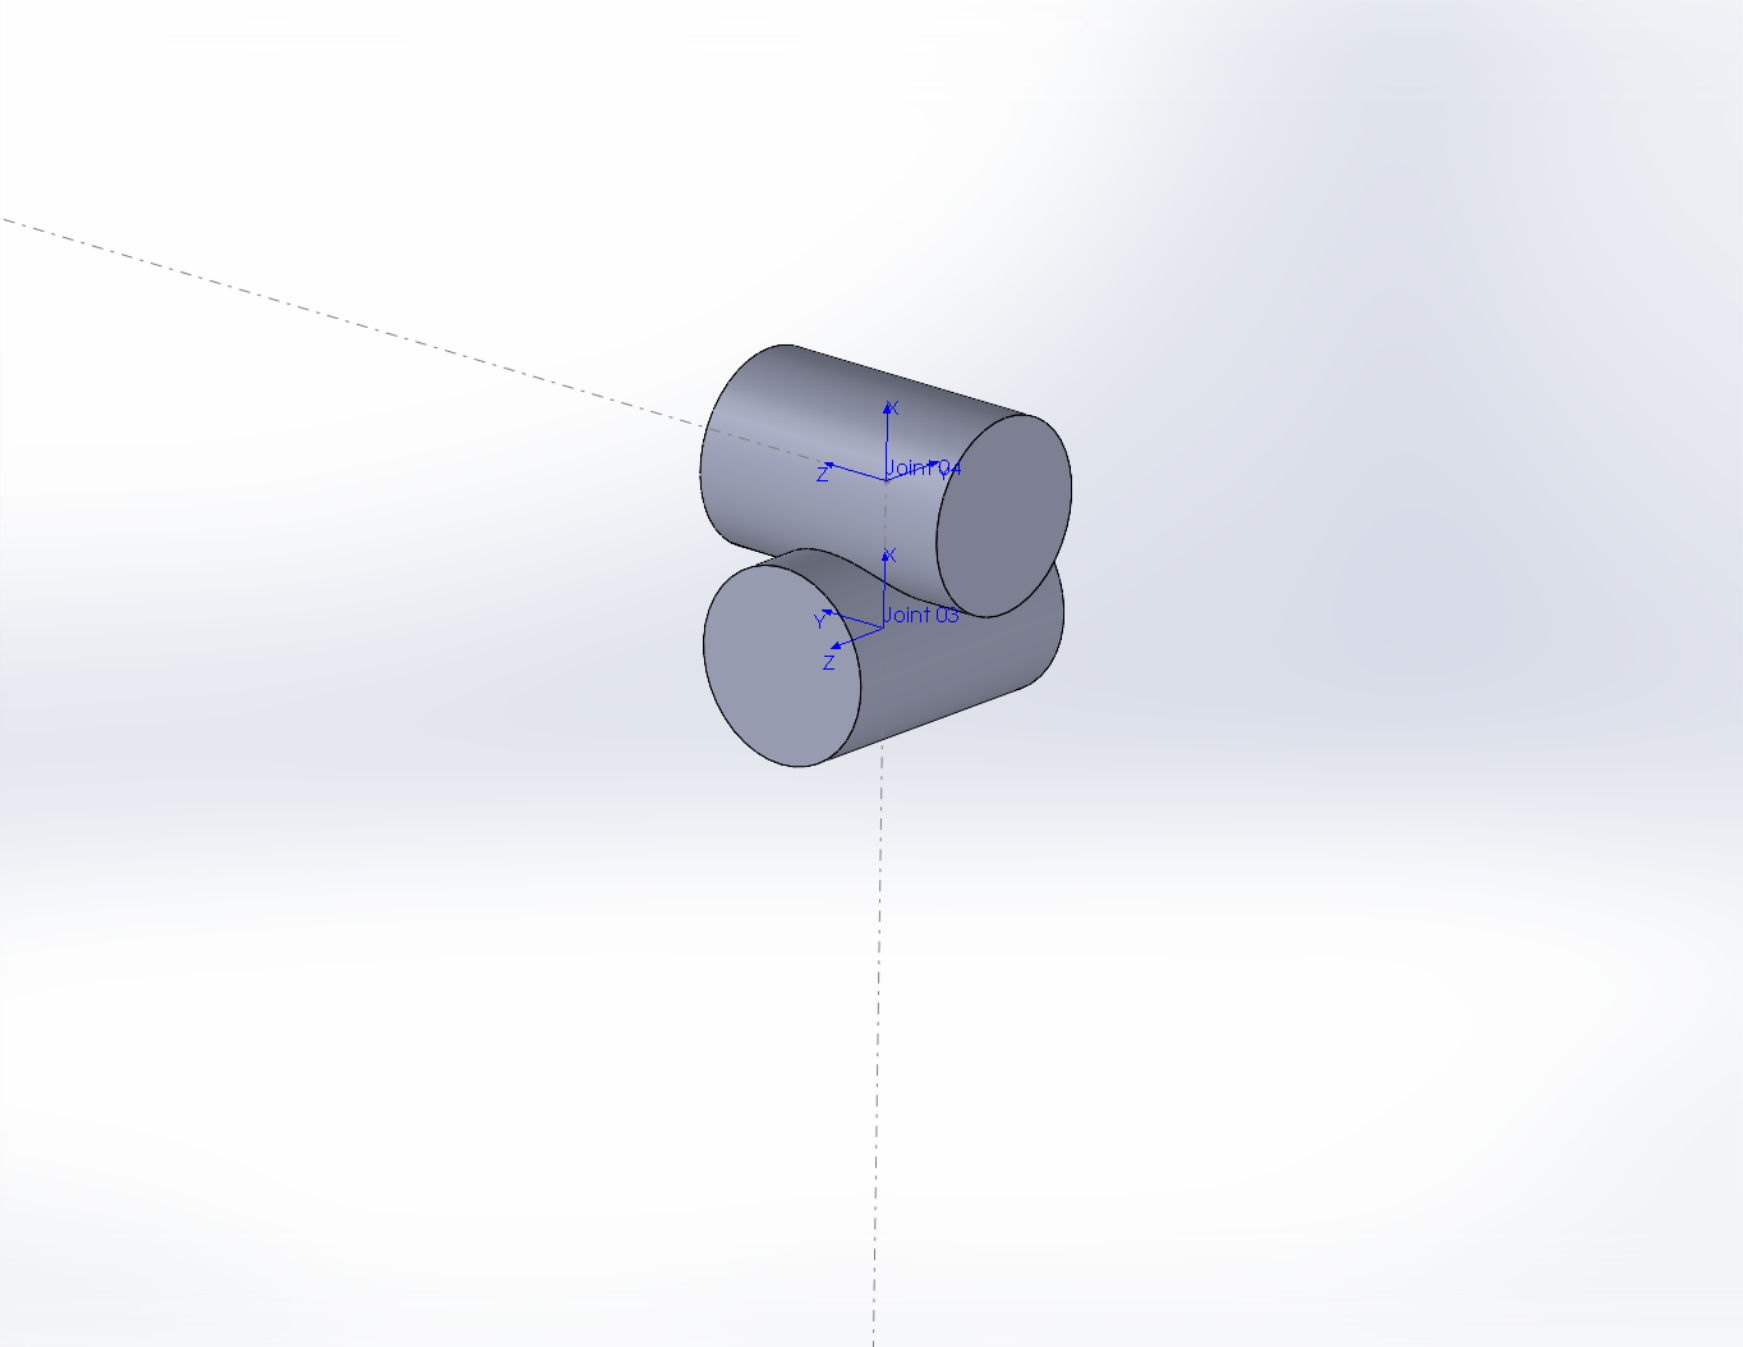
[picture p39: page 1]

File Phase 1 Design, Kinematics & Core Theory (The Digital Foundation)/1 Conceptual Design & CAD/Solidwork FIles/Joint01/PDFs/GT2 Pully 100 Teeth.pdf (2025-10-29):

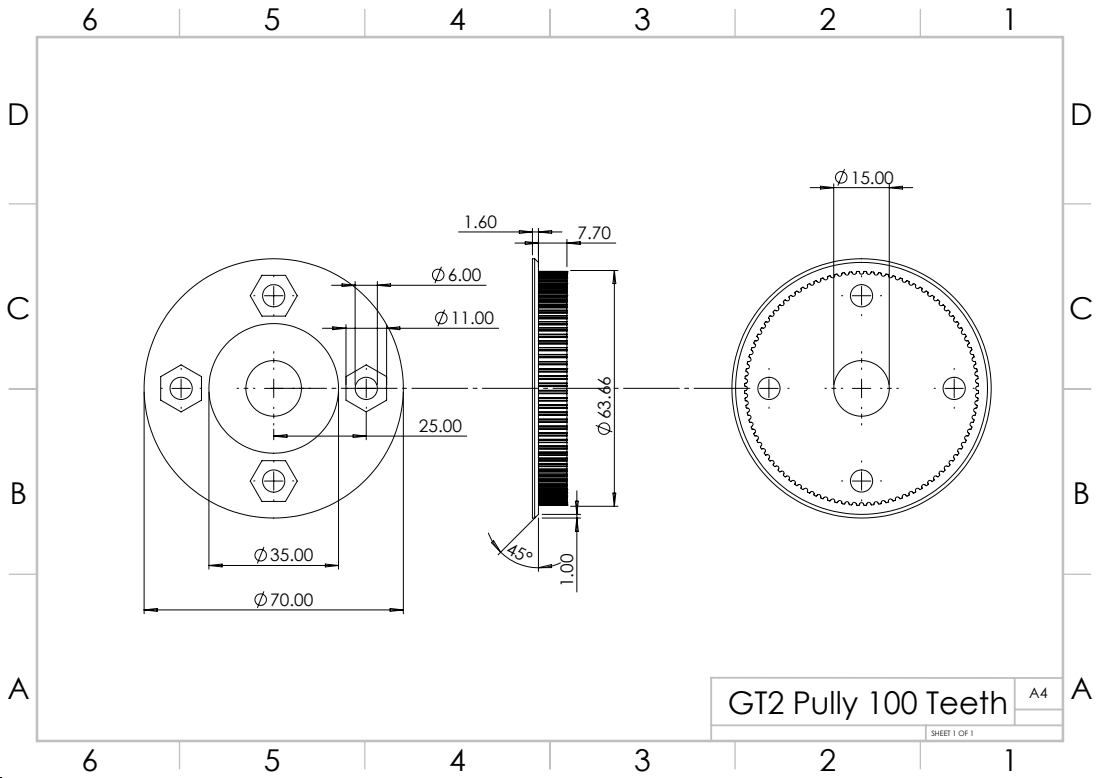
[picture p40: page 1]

A4 GT2 Pully 100 Teeth

SHEET 1 OF 1
